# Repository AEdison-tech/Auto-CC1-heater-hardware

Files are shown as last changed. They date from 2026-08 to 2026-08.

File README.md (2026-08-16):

# Elegoo Centauri Carbon automatic chamber heater — hardware

**Hardware** repository for **[Auto-CC1-heater-firmware](https://github.com/AEdison-tech/Auto-CC1-heater-firmware)** — an ESP32-C3 controller that automatically heats a printer's enclosure by watching the CC1's WebSocket status, driving a relay heater + fan with hysteresis temperature control.

This repository documents the physical build: a salvaged "Mini Heater" enclosure rebuilt around a custom control PCB, a PTC ceramic heating element and a fan, all driven by the ESP32-C3 firmware.

---

## Finished unit

| | |
|---|---|
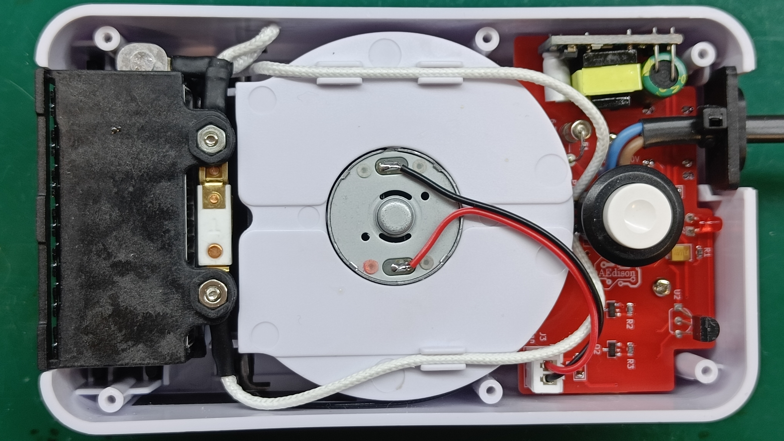
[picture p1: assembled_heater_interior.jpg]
Interior
| Finished heater |  |

The donor device is a cheap "Mini Heater" (see below) — its case, heating element and fan are reused, while the internal electronics are replaced with a custom PCB (see [`/PCB`](PCB)) running the [firmware](https://github.com/AEdison-tech/Auto-CC1-heater-firmware).

## Custom control PCB

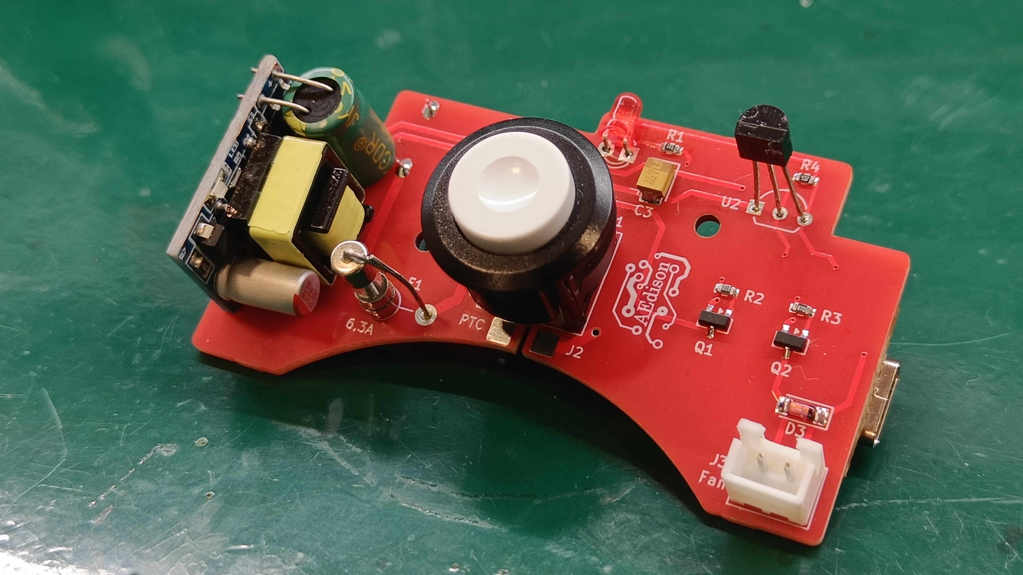
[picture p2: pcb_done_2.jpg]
PCB populated


| | |
|---|---|
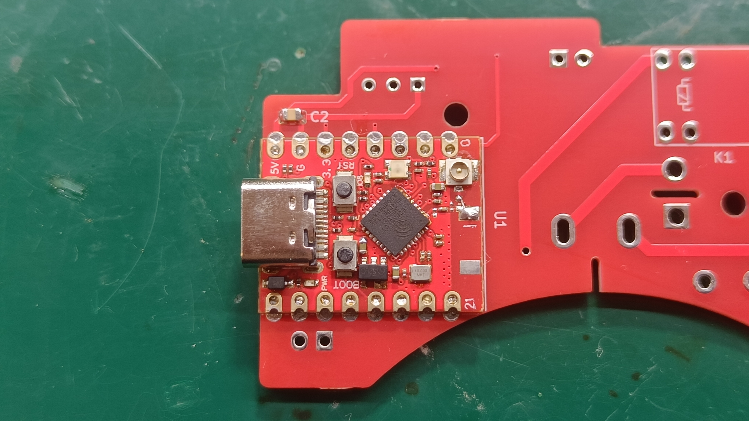
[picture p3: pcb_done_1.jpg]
ESP32-C3 module close-up
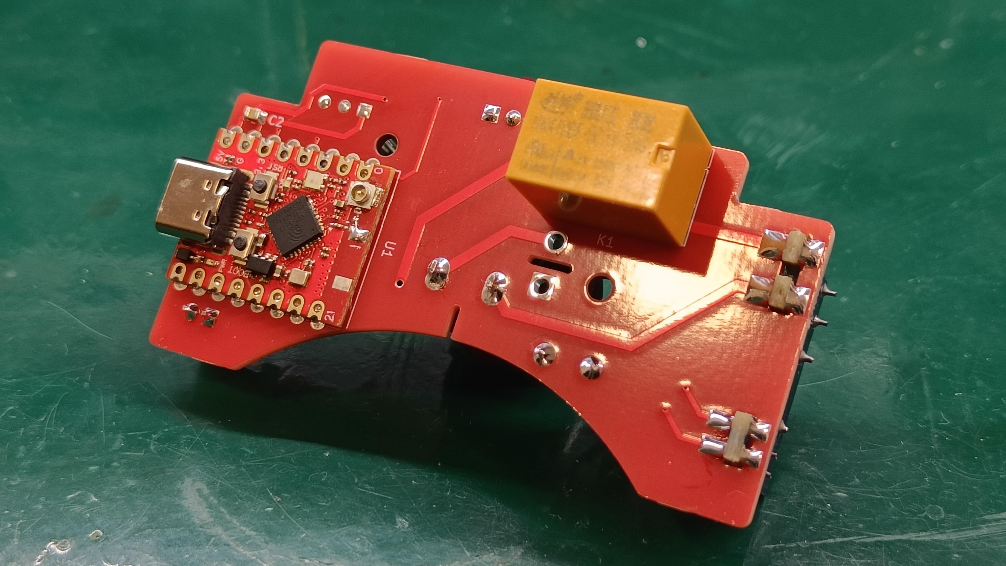
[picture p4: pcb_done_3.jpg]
PCB populated top
|  |  |

The board carries the ESP32-C3 module, a relay for the PTC element, MOSFET drivers for the fan and status LED, a thermistor input and a small isolated mains-to-5V supply for the logic side.

## Donor unit & case modification

| | | |
|---|---|---|
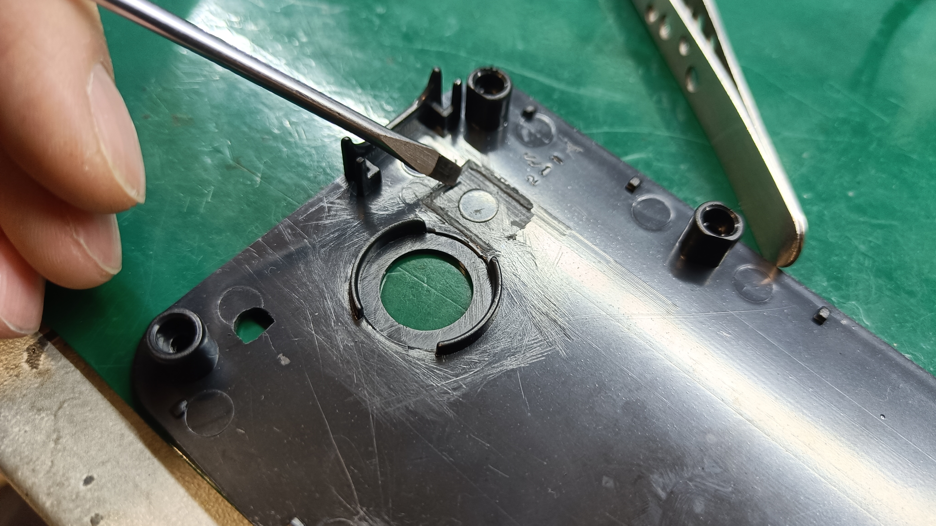
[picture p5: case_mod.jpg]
Case modification
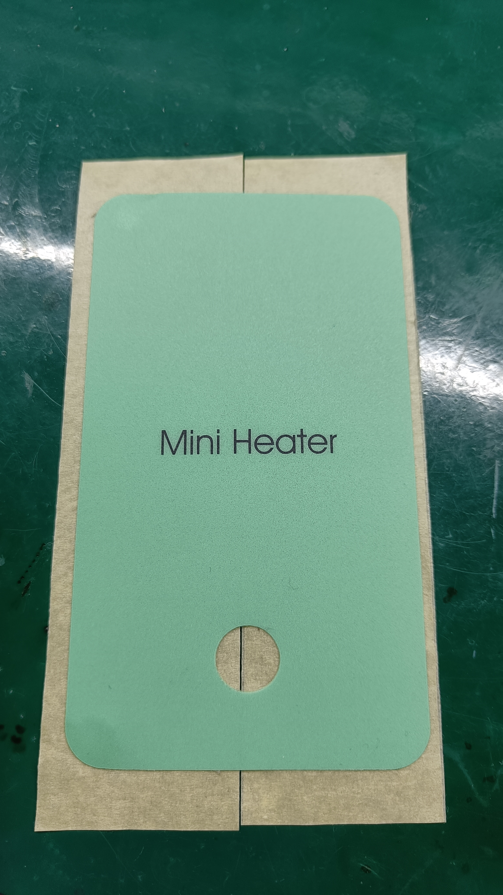
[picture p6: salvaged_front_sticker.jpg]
Salvaged front sticker
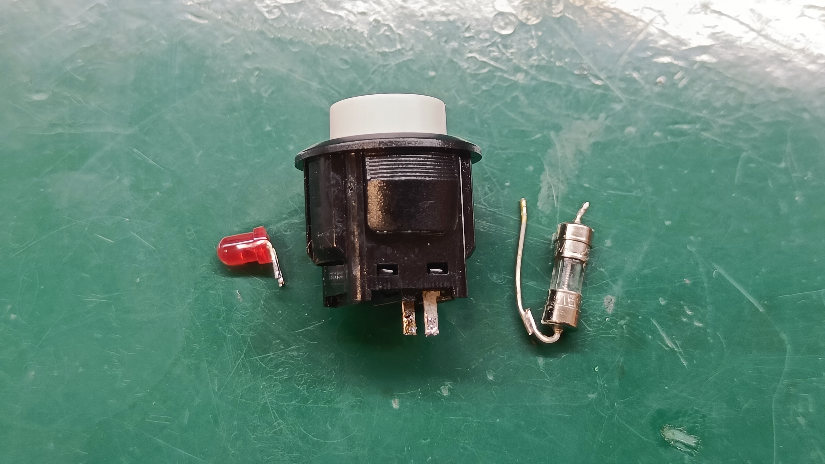
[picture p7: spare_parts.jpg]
Spare parts
|  |  |  |

This build starts from a cheap [heating fan bought on Amazon](https://www.amazon.com/Heating-Electric-Heater-Bracket-Office/dp/B0DX1RNQML). The original control board is discarded — only the switch, indicator LED and glass fuse are salvaged and reused on the new custom PCB, alongside the original front sticker.

The listing is available in both 230 V and 110 V variants — it doesn't matter which one is bought, the internals are identical. Since the PTC heating element is self-regulating by temperature, the only real difference between the two voltage variants is the cold-start peak current draw.

Fitting the new PCB into the original enclosure required a small case modification: on the back of the top plastic cover, a mounting nub that used to hold the original connector has to be broken/filed off — the connector itself is no longer used, and the nub would otherwise be in the way.

The case also needs two holes cut by hand: one for the temperature sensor, and one on the side for USB access. Exact positions aren't documented — they were milled into the case "by eye". If this project ever takes off, a 3D-printed drilling template showing the exact hole positions and sizes might happen — but that's a fair bit of extra work for now 🙂

## Logic power supply module

| | |
|---|---|
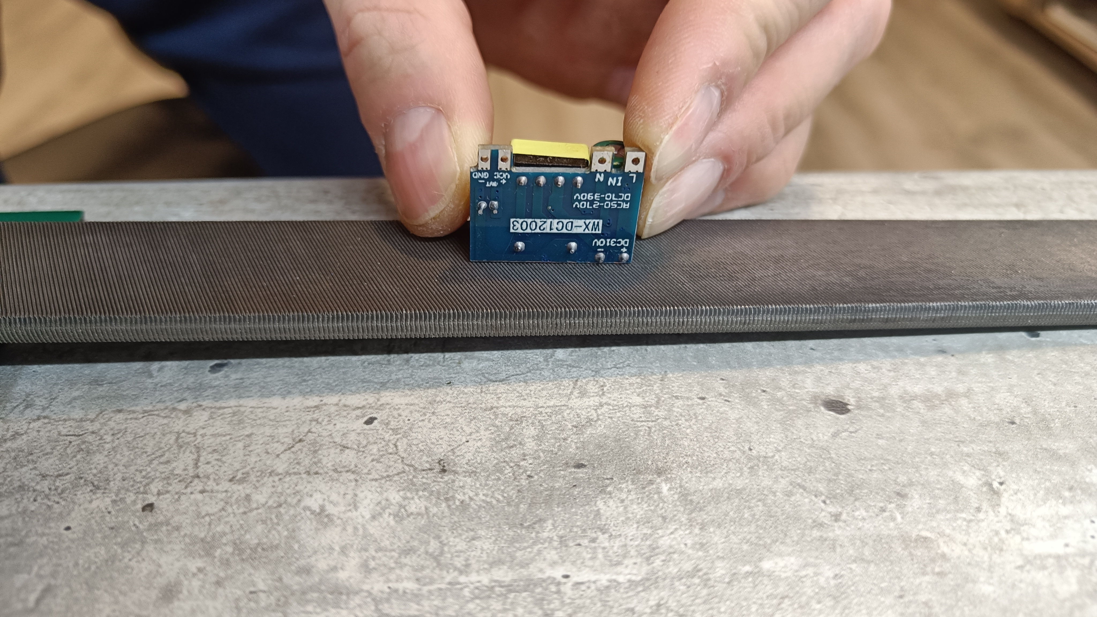
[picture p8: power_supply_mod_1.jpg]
Power supply module 1
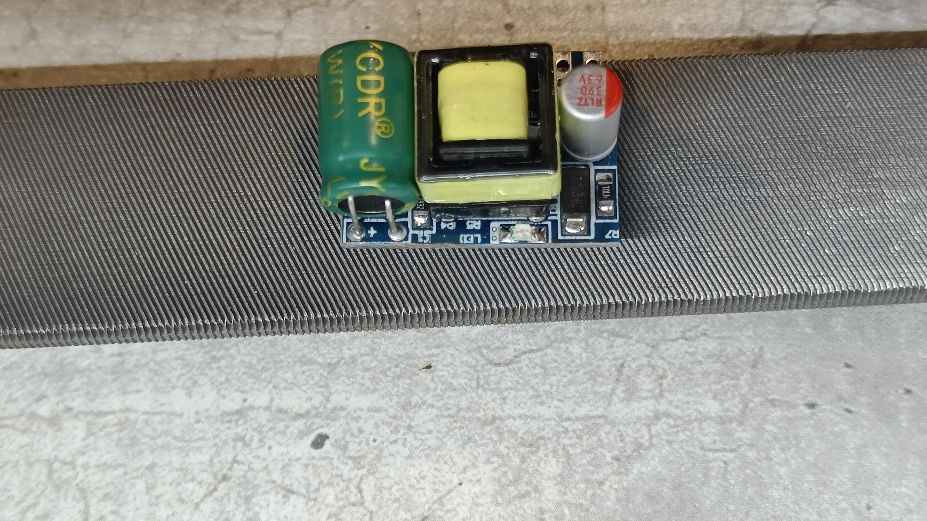
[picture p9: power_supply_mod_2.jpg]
Power supply module 2
|  |  |

Low-voltage logic power (5 V / 700 mA, 3.5 W) is provided by a small isolated mains-to-DC module (`WX-DC12003`), soldered directly onto the main PCB (footprint `PS1`).

- Module used: [AliExpress listing](https://www.aliexpress.com/item/4000837048338.html?spm=a2g0o.order_list.order_list_main.36.50711802VtwlVK).
- The module is roughly 0.5 mm taller than the available space inside the enclosure. This is fixed by sanding down ~0.5 mm from the top side of the module, right where the status LED sits — there are no traces or solder joints in that area, so it can be sanded flat without damaging the module (see photos above for exactly where to remove material).

## PTC heating element & wiring

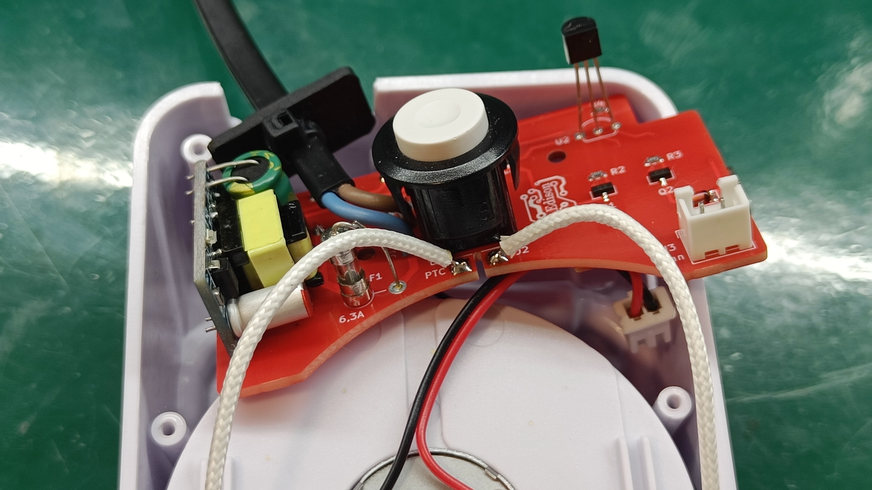
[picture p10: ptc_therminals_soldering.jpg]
PTC terminals soldering


Given the isolation clearances around the mains section and the surrounding component layout, soldering the leads directly onto the pads, as shown above, was the only way to make the connection work.

## 3D-printed cable spacer

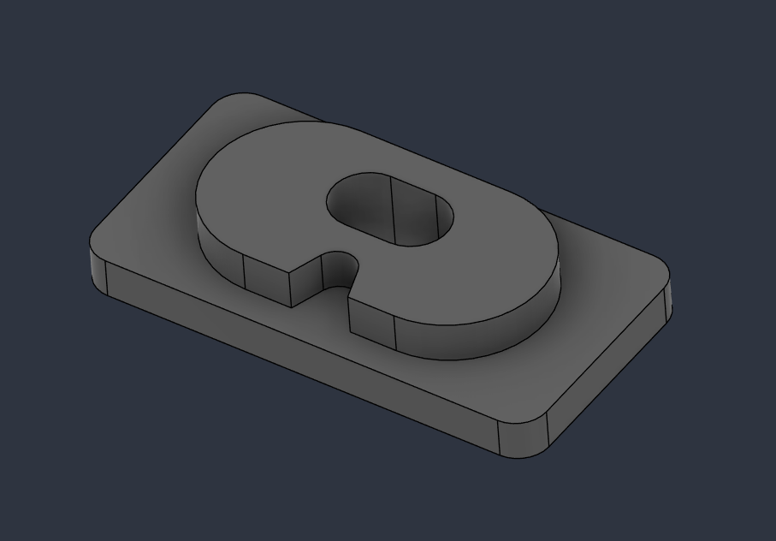
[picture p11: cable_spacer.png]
Cable spacer


A small 3D-printed spacer guides the mains cable through the enclosure wall. Source files are included in this repo:

- [`Heater cable spacer.f3d`](Heater%20cable%20spacer.f3d) — Fusion 360 project
- [`Cable_spacer.stl`](Cable_spacer.stl) — ready-to-print STL

It's recommended to secure the cable with a zip tie right behind the spacer, on the inside, to prevent it from being pulled out.

## Connecting to the printer

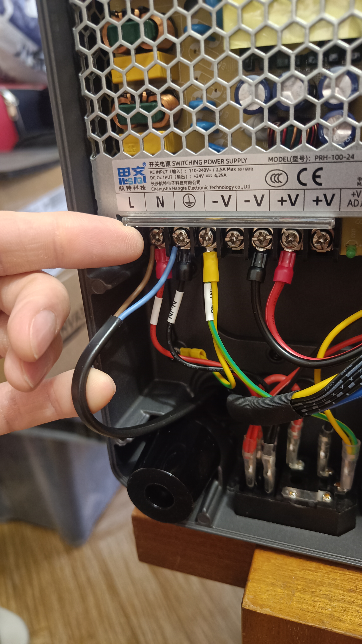
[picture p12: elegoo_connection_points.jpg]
Connection points


When wiring the finished heater into the printer's own power distribution, the printer's internal power-supply terminal block is the more suitable connection point from a current-distribution standpoint, compared to tapping power elsewhere in the printer.

> **⚠️ Fuse rating:** the CC1 ships with a 10 A input fuse. The PTC element can draw up to ~7 A cold-start inrush current, and if this coincides with the print bed heater also being active, the combined current can trip (or blow) the stock 10 A fuse. This hasn't happened during testing so far, but replacing the stock fuse with a **15 A** fuse is recommended.

---

## Related

- Firmware: [AEdison-tech/Auto-CC1-heater-firmware](https://github.com/AEdison-tech/Auto-CC1-heater-firmware)
- PCB design, gerbers & manufacturing notes: [`/PCB`](PCB)

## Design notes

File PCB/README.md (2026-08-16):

# Control PCB

Custom control board for the [Elegoo Centauri Carbon chamber heater](../README.md).

| Front | Back |
|---|---|
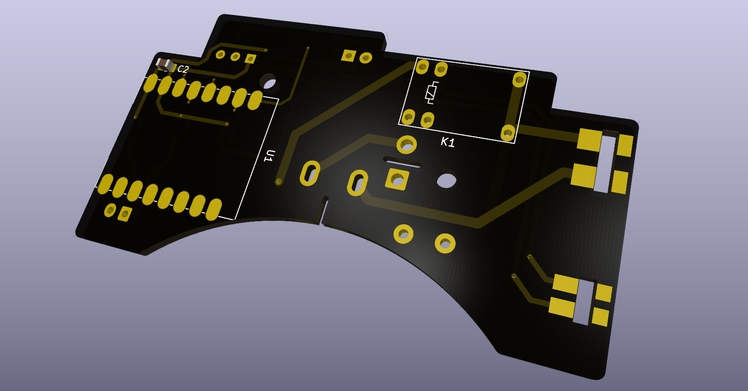
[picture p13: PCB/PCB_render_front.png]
PCB render — front
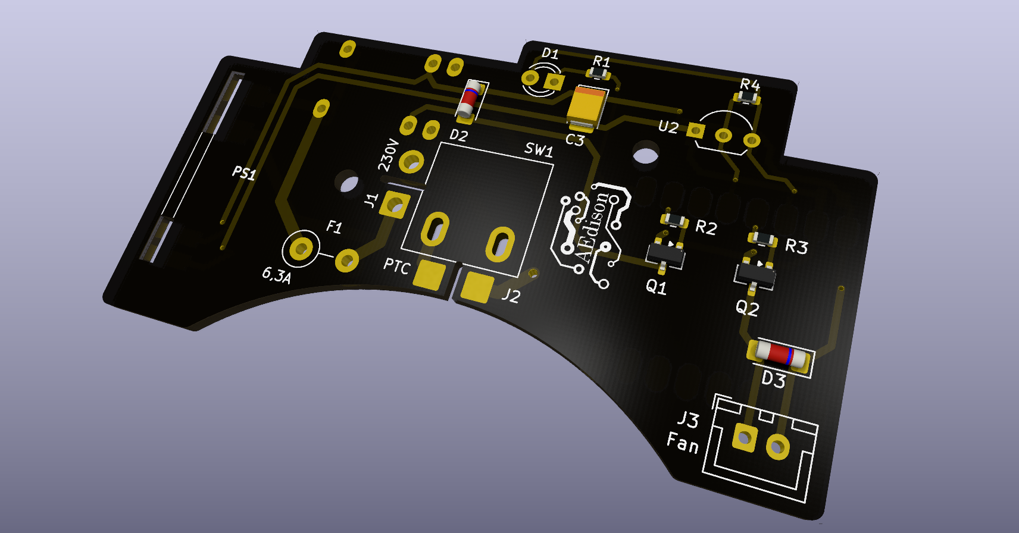
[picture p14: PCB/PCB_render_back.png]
PCB render — back
|  |  |

## Manufacturing

Gerber files for PCB production are included in this folder: [`Elegoo_heater_gerber.rar`](Elegoo_heater_gerber.rar).

Boards for this project were manufactured at [JLCPCB](https://jlcpcb.com/).

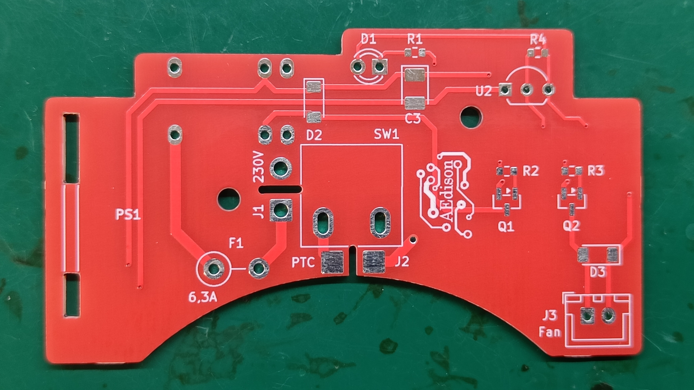
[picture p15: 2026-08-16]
PCB/front.jpg

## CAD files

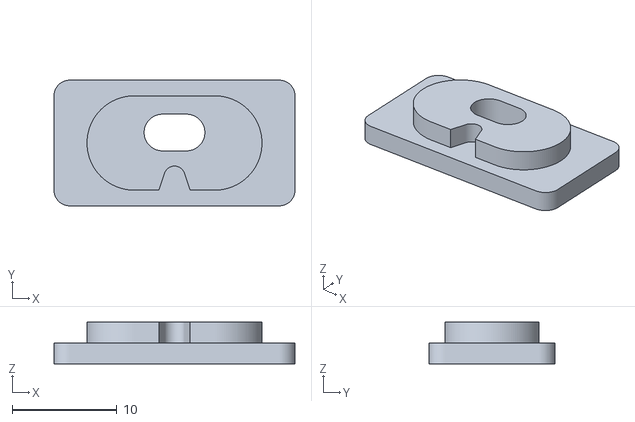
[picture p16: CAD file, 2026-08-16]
Cable_spacer.stl
23.0 x 12.0 x 4.00

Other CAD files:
Heater cable spacer.f3d
